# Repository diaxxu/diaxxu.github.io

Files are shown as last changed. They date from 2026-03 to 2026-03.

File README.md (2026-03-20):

#  DROP POD — Precision Aerial Delivery System

Capture d'écran 2026-03-20 113256

<p align="center">
  
  
  
  
  
</p>

---

> **A fully autonomous, GPS + vision-guided drop pod** carried under the wing of an RC aircraft. Released on operator command, it navigates to a red carpet landing zone using GPS macro-guidance and nose-mounted optical terminal tracking — nose-first impact, cushion-assisted landing. No propulsion. No parachute. Pure precision.

---

##  Table of Contents

1. [What This Is](#what-this-is)
2. [How It Works](#how-it-works)
3. [System Architecture](#system-architecture)
4. [Hardware Requirements](#hardware-requirements)
5. [Software Stack](#software-stack)
6. [Directory Structure](#directory-structure)
7. [Quick Start](#quick-start)
8. [Wiring Guide](#wiring-guide)
9. [Configuration](#configuration)
10. [Flight Operations](#flight-operations)
11. [Tuning Guide](#tuning-guide)
12. [Safety & Legal](#safety--legal)
13. [Contributing](#contributing)
14. [Roadmap](#roadmap)
15. [Team & Credits](#team--credits)

---

## What This Is

The **Drop Pod** is a passively propelled, actively guided aerial payload delivery system. It is:

- **Carried** under the wing of any medium RC aircraft (minimum 1.5 kg payload capacity)
- **Released** on operator command (RC transmitter aux channel or GCS MAVLink command)
- **Self-guided** using onboard GNSS to the target zone
- **Optically locked** onto a red carpet marker using a nose-mounted camera running real-time OpenCV detection
- **Nose-impact landed** — the pod dives nose-first onto the cushioned target

**Phase 1 scope (this repository):** GPS approach + optical lock + direct nose-impact. No flare. No glide slope. Ground team places a foam/air cushion on the red carpet. The pod hits it clean.

---

## How It Works

```
┌─────────────────────────────────────────────────────────────────┐
│                        MISSION TIMELINE                         │
└─────────────────────────────────────────────────────────────────┘

  [GROUND]                [IN-AIR]                    [TERMINAL]
  
  Load target GPS    →   Carrier delivers pod   →   Pod descends
  Arm system             over drop zone             GPS-guided
  Confirm carpet         ↓                          ↓
  is in range            Operator sends             At ~40m AGL:
  ↓                      ARM → DROP                 Camera activates
  Cushion placed         ↓                          Red carpet locked
  on carpet              Reachability check         Optical steering
                         passes                     ↓
                         ↓                          Nose-impact on
                         Latch fires                cushion ✓
                         Pod separates
```

### Phase Breakdown

| Phase | Mode | Altitude | Trigger |
|---|---|---|---|
| **Idle** | Passive on wing | Any | — |
| **Armed** | Monitoring | Any | ARM command |
| **Released** | Stabilised descent | Drop alt | DROP command + reach check |
| **GPS Approach** | GNSS-guided | Drop → 40 m AGL | Automatic post-release |
| **Optical Lock** | Camera tracking | 40 m → impact | Barometer threshold |
| **Landed** | Inert | 0 | Impact detection (accel) |

---

## System Architecture

```
┌────────────────────────────────────────────────────────────┐
│                    DROP POD INTERNALS                      │
│                                                            │
│  [NOSE — CAMERA]                                           │
│  ┌─────────────────────────────────────┐                   │
│  │  RPi Camera Module 3 (CSI-2)        │ ← Nose tip        │
│  │  IMX708 · 102° FOV · 30fps          │   looking forward │
│  └──────────────┬──────────────────────┘                   │
│                 │ CSI ribbon                               │
│  [FORWARD SECTION — COMPUTE + FINS]                        │
│  ┌──────────────▼──────────────────────┐                   │
│  │  Raspberry Pi Zero 2W               │ ← Vision + FSM    │
│  │  ├─ mission_manager.py              │                   │
│  │  ├─ vision.py (OpenCV)              │                   │
│  │  └─ UART → FC (MAVLink/MSP)         │                   │
│  │                                     │                   │
│  │  Matek F405-WING (ArduPlane)        │ ← PID + Servos    │
│  │  ├─ IMU ICM-42688 (SPI)             │                   │
│  │  ├─ GPS u-blox M10 (UART)          │                   │
│  │  ├─ Baro BMP388 (I2C)              │                   │
│  │  └─ 4× Servo PWM outputs           │                   │
│  │                                     │                   │
│  │  4× Canard Fins (cruciform)         │ ← Actuation       │
│  │  Emax ES9051 · 2.0 kg·cm           │                   │
│  └─────────────────────────────────────┘                   │
│                                                            │
│  [MID SECTION — POWER + COMMS]                             │
│  ┌─────────────────────────────────────┐                   │
│  │  3S 1000mAh LiPo (11.1V)           │ ← Main power       │
│  │  Pololu 5V BEC ×2                   │                   │
│  │  ELRS Receiver (2.4GHz SBUS)        │ ← RC commands      │
│  │  SiK 915MHz Telemetry               │ ← GCS MAVLink      │
│  └─────────────────────────────────────┘                   │
└────────────────────────────────────────────────────────────┘
```

### Inter-Processor Communication

```
RC TX (pilot)  ──SBUS──►  ELRS Receiver ──SBUS──► F405 FC
                                                      │
GCS (laptop)   ──MAVLink/915MHz──────────────────────►│
                                                      │
                                            F405 FC ◄─┤─► 4× Servo (PWM 400Hz)
                                               │      │
                                           UART/MSP   │
                                               │      │
                                        RPi Zero 2W   │
                                               │      │
                                         CSI-2 │      │
                                               │      │
                                        Camera Module  │
```

---

## Hardware Requirements

See [BOM.csv](BOM.csv) for complete sourcing list. Summary:

| # | Component | Purpose | Est. Cost |
|---|---|---|---|
| 1 | **Matek F405-WING** | Flight controller, PID, servo output | $35 |
| 2 | **Raspberry Pi Zero 2W** | Vision compute, mission FSM | $15 |
| 3 | **RPi Camera Module 3 Wide** | Nose-mounted target tracking | $25 |
| 4 | **u-blox M10 GPS** | GNSS macro-approach guidance | $30 |
| 5 | **ICM-42688-P IMU** | Attitude estimation (may be on FC) | $8 |
| 6 | **BMP388 Barometer** | AGL altitude for camera activation | $5 |
| 7 | **SiK 915MHz Radio ×2** | GCS MAVLink telemetry + uplink | $30 |
| 8 | **ELRS Receiver** | RC TX commands (ARM/DROP) | $12 |
| 9 | **9g Digital Servo ×5** | 4× fin + 1× wing latch | $20 |
| 10 | **3S 1000mAh LiPo** | Main power | $18 |
| 11 | **Pololu 5V BEC ×2** | Regulated power rails | $10 |
| 12 | **CF Tube ø80×320mm** | Main fuselage | $15 |
| 13 | **PETG/PLA Filament** | Printed structure parts | $10 |
| **Total** | | | **~$233** |

### Carrier Aircraft Requirements

- Minimum payload capacity: **800g** (pod target mass ≤ 650g)
- Wing hardpoint or pod-rail mounting point
- Free aux channel on RC TX for release servo
- Stable flight at 12–22 m/s

---

## Software Stack

| Layer | Technology | Purpose |
|---|---|---|
| Flight controller | ArduPlane (STM32) | PID, servo mixing, GPS nav |
| Vision + FSM | Python 3.11 on RPi | OpenCV, mission state machine |
| Inter-proc comms | MAVLink over UART | Pi ↔ FC bidirectional |
| GCS | Mission Planner / MAVProxy | Ground control, telemetry display |
| Configuration | YAML + .param files | All tunable params in one place |

---

## Directory Structure

```
drop-pod/
│
├── README.md                    ← You are here
├── BOM.csv                      ← Full bill of materials with sourcing
├── LICENSE                      ← MIT License
│
├── software/                    ← All Python code for RPi
│   ├── requirements.txt         ← pip dependencies
│   ├── config.py                ← Central configuration (all tunable params)
│   ├── mission_manager.py       ← Main mission FSM — entry point
│   ├── vision.py                ← OpenCV red carpet detection pipeline
│   ├── guidance.py              ← Reachability check + GPS math
│   └── comms.py                 ← MAVLink interface (FC + GCS)
│
├── firmware/
│   ├── params/
│   │   └── drop_pod.param       ← ArduPlane parameter file (load via MP)
│   └── lua/
│       └── vision_inject.lua    ← ArduPlane Lua: ingest Pi corrections
│
├── hardware/
│   ├── stl/
│   │   ├── README.md            ← Print settings for every part
│   │   ├── nose_camera_mount.stl
│   │   ├── fin_mount_forward.stl
│   │   ├── fin_blade.stl
│   │   ├── servo_bay_cover.stl
│   │   ├── avionics_tray.stl
│   │   ├── power_bay.stl
│   │   └── tail_cap_camera_exit.stl   ← NOTE: camera is at nose, this is ballast
│   └── wiring/
│       └── wiring_diagram.md    ← Full pinout and wiring guide
│
├── docs/
│   ├── MECHANICAL.md            ← Dimensions, CG, fin geometry
│   ├── ASSEMBLY.md              ← Step-by-step build guide
│   ├── TUNING.md                ← PID tuning procedure
│   ├── SAFETY.md                ← Pre-flight checklist, regulations
│   └── FLIGHT_OPS.md            ← Field operations manual
│
└── .github/
    └── CONTRIBUTING.md          ← How to contribute
```

---

## Quick Start

### 1. Clone the Repository

```bash
git clone https://github.com/your-org/drop-pod.git
cd drop-pod
```

### 2. Set Up the Raspberry Pi Zero 2W

```bash
# Flash Raspberry Pi OS Lite (64-bit) onto SD card
# Enable SSH, I2C, SPI, Camera in raspi-config

# On the Pi:
sudo apt update && sudo apt install -y python3-pip python3-opencv libopencv-dev
cd /home/pi
git clone https://github.com/your-org/drop-pod.git
cd drop-pod/software
pip3 install -r requirements.txt

# Edit config before first run
nano config.py
```

### 3. Configure the Flight Controller

```
1. Flash ArduPlane latest stable to your F405
2. Open Mission Planner → Full Parameter List
3. Load firmware/params/drop_pod.param
4. Calibrate: accelerometer, compass, radio
5. Set SERVO1..4 outputs to match your fin wiring
```

### 4. Connect Telemetry

```bash
# On ground laptop:
mavproxy.py --master=/dev/ttyUSB0 --baudrate=57600 --out=udp:127.0.0.1:14550
# Open Mission Planner → connect UDP 14550
```

### 5. Set Target Coordinates

```python
# In software/config.py:
TARGET_LAT  = 33.5731  # Decimal degrees
TARGET_LON  = -7.5898
TARGET_ALT  = 0.0      # MSL in metres (ground elevation)
```

### 6. Pre-Flight Checklist

See [docs/SAFETY.md](docs/SAFETY.md) for complete pre-flight checklist.

---

## Wiring Guide

See [hardware/wiring/wiring_diagram.md](hardware/wiring/wiring_diagram.md) for complete pinout.

Quick reference:

```
F405 FC                     RPi Zero 2W
──────────                  ──────────
TX1 (UART1) ─────────────► RX (GPIO15 / UART0)
RX1 (UART1) ◄───────────── TX (GPIO14 / UART0)
GND ─────────────────────── GND

F405 FC                     ELRS Receiver
──────────                  ─────────────
RX2 (UART2) ◄───────────── SBUS OUT
5V BEC ─────────────────── 5V
GND ─────────────────────── GND

F405 FC                     u-blox M10 GPS
──────────                  ──────────────
TX3 (UART3) ─────────────► RX
RX3 (UART3) ◄───────────── TX
5V ─────────────────────── 5V
GND ─────────────────────── GND

F405 FC                     Servos (×4 fins + 1 latch)
──────────                  ──────────────────────────
S1 ────────────────────────► FIN TOP (signal)
S2 ────────────────────────► FIN BOTTOM (signal)
S3 ────────────────────────► FIN LEFT (signal)
S4 ────────────────────────► FIN RIGHT (signal)
S5 ────────────────────────► LATCH SERVO (on carrier aircraft)
Servo BEC 5V ──────────────► All servo 5V rails (common)
GND ───────────────────────► All servo GND (common)
```

---

## Configuration

All mission-tunable parameters live in `software/config.py`:

```python
# ── MISSION ──────────────────────────────────────────────
TARGET_LAT          = 33.5731       # Target latitude
TARGET_LON          = -7.5898       # Target longitude
TARGET_ALT_MSL      = 0.0           # Ground elevation MSL (m)

# ── REACHABILITY ─────────────────────────────────────────
GLIDE_RATIO         = 4.0           # Conservative glide ratio
SAFETY_MARGIN       = 0.85          # Use only 85% of max range
MAX_WIND_SPEED      = 8.0           # m/s — abort above this

# ── PHASE TRANSITIONS ────────────────────────────────────
CAMERA_ACTIVATE_AGL = 40.0          # metres — switch to optical
MIN_LOCK_CONFIDENCE = 0.80          # 0.0–1.0, red carpet lock threshold

# ── VISION ───────────────────────────────────────────────
CAM_FOV_H_DEG       = 102.0         # Camera horizontal FOV
CAM_FOV_V_DEG       = 67.0          # Camera vertical FOV
CAM_RESOLUTION      = (1280, 720)   # Capture resolution
CAM_FPS             = 30            # Target frame rate
HSV_RED_LOW_1       = (0,   120, 80)    # Red mask range 1 lower
HSV_RED_HIGH_1      = (12,  255, 255)   # Red mask range 1 upper
HSV_RED_LOW_2       = (165, 120, 80)    # Red mask range 2 lower
HSV_RED_HIGH_2      = (180, 255, 255)   # Red mask range 2 upper
MIN_CARPET_AREA_PX  = 800           # Min blob pixels to count as lock

# ── GUIDANCE GAINS ───────────────────────────────────────
KV_LATERAL          = 0.4           # Vision lateral correction gain
KV_PITCH            = 0.15          # Vision pitch correction gain

# ── COMMUNICATION ────────────────────────────────────────
FC_UART_PORT        = "/dev/serial0"
FC_UART_BAUD        = 115200
TELEM_BAUD          = 57600
HEARTBEAT_INTERVAL  = 0.5           # seconds
```

---

## Flight Operations

### Pre-Mission Checklist (Field)

```
□ Battery voltage > 12.0V (3S full = 12.6V)
□ GPS 3D fix acquired, HDOP < 2.0
□ All 4 fins deflect correctly (servo test)
□ Camera feed active, red carpet detected in bench test
□ Telemetry link established on GCS
□ Target coordinates loaded and verified
□ Red carpet placed at target, cushion on top
□ Drop zone clear of personnel (minimum 30m radius)
□ Weather: wind < 8 m/s, no rain
□ Carrier aircraft pre-flight complete
□ Carrier release servo tested (WITHOUT pod attached)
```

### Drop Sequence

```
1. Carrier aircraft takes off, climbs to mission altitude (min 60m AGL)
2. Pilot flies over or near drop zone
3. GCS operator confirms pod GPS position and range
4. Operator sends: ARM command (TX Ch7 HIGH or GCS button)
5. GCS shows: "POD ARMED — REACHABILITY CHECK ACTIVE"
6. If target in range: GCS shows "IN RANGE — SAFE TO DROP"
7. Operator sends: DROP command (TX Ch8 HIGH or GCS button)
8. Pod releases, begins GPS-guided descent
9. At 40m AGL: GCS shows "CAMERA ACTIVE"
10. At lock: GCS shows "TARGET LOCKED — [confidence]%"
11. Pod impacts cushion on red carpet
12. GCS shows "LANDED" (accel spike detected)
```

### GCS Commands (MAVLink)

| Action | Mission Planner | MAVProxy CLI |
|---|---|---|
| ARM | Aux1 HIGH button | `param set RELAY_PIN1 1` |
| DROP | Aux2 HIGH button | `do_set_relay 1 1` |
| ABORT | Abort button | `mode GUIDED` |
| Update target | Right-click map → Set target | `guided LAT LON ALT` |

---

## Tuning Guide

See [docs/TUNING.md](docs/TUNING.md) for full procedure. Key steps:

1. **Bench test**: Verify all servos zero correctly with no power-on drift
2. **Hand-drop test**: Drop from 2m by hand. Verify fins stabilise attitude within 0.5s
3. **Low-altitude drop**: 15–20m from a tall pole or drone. Verify GPS tracks target
4. **Vision bench**: Move red carpet under camera. Verify centroid tracks correctly at 1m, 3m, 5m
5. **Full mission**: 60m+ drop with camera active at 40m. Evaluate impact accuracy

---

## Safety & Legal

 **Read [docs/SAFETY.md](docs/SAFETY.md) before any field test.**

- This system drops a ~650g object from altitude. Treat it as a **projectile**.
- Always operate in a **cleared, controlled area** with ground personnel outside the drop radius.
- **National regulations apply.** In EU: EASA UAS open/specific category rules. In the US: FAA Part 107 may require a waiver for dropping objects.
- Use the two-step ARM → DROP command sequence. Never skip ARM.
- The reachability check is a safety gate — **do not bypass it in code**.

---

## Roadmap

### Phase 1 — Current (This Repo)
- [x] GPS macro-approach guidance
- [x] Nose-camera optical red carpet lock
- [x] 4-fin canard attitude control
- [x] RC + GCS dual command interface
- [x] Reachability check with automatic abort
- [x] Nose-impact delivery (cushion-assisted)

### Phase 2 — Next
- [ ] RTK GPS for cm-level approach accuracy
- [ ] YOLOv8-nano detector replacing HSV (shadow-robust)
- [ ] LiDAR AGL sensor (TFMini) for precise altitude
- [ ] Controlled flare manoeuvre for softer landing

### Phase 3 — Future
- [ ] Two-way camera feed via 5.8GHz VTX
- [ ] Swappable payload bay
- [ ] Multiple concurrent pods on one carrier
- [ ] Sim-to-real training loop (Gazebo/AirSim)

---

## Contributing

See [.github/CONTRIBUTING.md](.github/CONTRIBUTING.md).

PRs welcome in these areas:
- Better PID initial values (share your tuning data)
- Alternative vision algorithms
- 3D model improvements
- Documentation translations
- Simulation environments (Gazebo/AirSim configs)

---
## License

MIT License — see [LICENSE](LICENSE). Free to use, modify, and build. Please credit the project.

---

<p align="center">
  <strong>DROP POD — OPEN SOURCE PRECISION DELIVERY</strong><br/>
  <em>If it can be guided, it can be landed precisely.</em>
</p>

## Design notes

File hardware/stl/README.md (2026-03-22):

# 3D Printed Parts — Print Settings & Assembly Guide
## Drop Pod Hardware Revision A

---

## Printer Requirements

| Parameter | Minimum | Recommended |
|---|---|---|
| Build volume | 100×100×100mm | 200×200×200mm |
| Layer resolution | 0.2mm | 0.15mm |
| Extruder temp | 230°C (PETG) | 240°C |
| Bed temp | - | 80°C |
| Bed surface | PEI/glass | PEI textured |

---

## Material

**Use PETG for ALL structural parts.** Do NOT use PLA.

| Property | PLA | PETG |
|---|-----|---|
| Impact resistance | Low | High |
| Heat deflection | ~60°C (warps in sun) | ~80°C |
| Layer adhesion | Medium | High |
| Price | Cheaper | Slightly more |

Impact resistance is critical — the pod noses into a cushion at speed. PETG absorbs impact energy significantly better than PLA.

---

## Parts List

### Part 01: `nose_camera_mount.stl`
**The nose of the pod — this IS the camera housing.**

```
Description : Cylindrical nose section, ø80mm OD, 85mm long.
              Camera Module 3 Wide seats in a recessed pocket at
              the very tip. CSI ribbon exits through a slot in
              the side wall toward the avionics bay.
              
Function    : Camera housing + aerodynamic nose fairing.
              The camera lens is flush with the front face.
              
Print settings:
  - Layer height : 0.15mm (critical for lens pocket accuracy)
  - Infill       : 40% gyroid
  - Walls        : 4 perimeters
  - Top/bottom   : 5 layers
  - Supports     : YES — needed for camera pocket recess
  - Orientation  : Print nose-tip UP for best surface quality on lens face
  
Post-processing:
  - Sand camera pocket with 400-grit until Camera Module 3
    sits flush with no wobble
  - Apply thin bead of hot glue around camera module edges
    to lock in place (do not glue over lens)
  - Thread CSI ribbon through side slot before gluing camera
  - Bond to CF tube with 30-min epoxy. Align with fin mount slots.
```

### Part 02: `fin_mount_forward.stl`
**Servo bay ring — slides into CF tube, holds 4 servos.**

```
Description : Ring-shaped collar, ø80mm OD to match CF tube ID.
              Four servo pockets, cruciform pattern at 90° spacing.
              Servo horns face inward.
              
Print settings:
  - Layer height : 0.2mm
  - Infill       : 60% gyroid (strength critical)
  - Walls        : 5 perimeters
  - Top/bottom   : 5 layers
  - Supports     : Minimal — servo pockets may need tree supports
  - Orientation  : Print in the mounting orientation (ring flat on bed)

Post-processing:
  - Test-fit all 4 servos before final assembly
  - Drill out M3 screw holes with 3.2mm drill bit if tight
  - Apply Loctite 243 to all servo mount screws
```

### Part 03: `fin_blade.stl`
**Canard fin — print 4 identical copies.**

```
Description : Trapezoidal fin blade, 55mm span × 40mm chord.
              NACA 0009 profile (symmetrical, zero camber).
              Servo horn attachment slot at root.
              Pushrod clevis attachment hole at trailing edge root.
              
Print settings:
  - Layer height : 0.15mm (profile accuracy)
  - Infill       : 30% triangles (strong in bending)
  - Walls        : 4 perimeters
  - Top/bottom   : 4 layers
  - Supports     : None needed
  - Orientation  : Print FLAT on bed (fin in horizontal plane)
  - Note         : Print ALL FOUR in same batch for matching mass

Post-processing:
  - Sand trailing edge to sharp edge with 400-grit
  - Check all 4 fins have same mass (±0.5g). Add tiny epoxy
    drops to lighter fins to balance.
  - Attach servo horn to root slot. Use M2 screw + Loctite.
```

### Part 04: `servo_bay_cover.stl`
**Aesthetic/protective cover over the servo bay area.**

```
Description : Thin cylindrical skin section, 80mm OD × 50mm long.
              Four slots cut for fin root protrusion.
              Snaps over fin_mount_forward.
              
Print settings:
  - Layer height : 0.2mm
  - Infill       : 20%
  - Walls        : 3 perimeters
  - Supports     : None
  - Orientation  : Vertical (cylinder axis vertical on bed)
```

### Part 05: `avionics_tray.stl`
**Internal mounting tray for FC, Pi, GPS.**

```
Description : Rectangular tray, 70mm × 150mm × 10mm.
              Slots for M3 nylon standoffs at FC and Pi footprints.
              Slides into CF tube and is retained by M3 screws
              through the CF tube wall.
              
Print settings:
  - Layer height : 0.2mm
  - Infill       : 40% gyroid
  - Walls        : 4 perimeters
  - Supports     : None
  - Orientation  : Flat on bed

Component placement on tray (front to back):
  [0mm]   GPS module (UART3, antenna pointing up through hole in tray)
  [30mm]  F405 FC (SPI/I2C sensors connect here)
  [80mm]  RPi Zero 2W (UART0 → FC UART1)
  [130mm] SiK radio module
```

### Part 06: `power_bay.stl`
**Battery bay and BEC holder — rear section of pod.**

```
Description : Cylindrical section, 80mm OD × 90mm long.
              Battery cradle sized for 3S 1000mAh (18×35×72mm approx).
              Two BEC holders on sides.
              XT30 port slot at rear.
              
Print settings:
  - Layer height : 0.2mm
  - Infill       : 35%
  - Walls        : 4 perimeters
  - Supports     : YES for battery cradle lip
  - Orientation  : Print with XT30 port face UP

Battery retention:
  - Two Velcro straps through slots in cradle
  - Do NOT rely on friction alone — battery must not shift under impact
```

### Part 07: `tail_ballast_cap.stl`
**Rear end cap with ballast weight pocket.**

```
Description : Domed end cap, 80mm OD.
              Central ballast pocket for tungsten or steel slug.
              Plug-in fit with rubber O-ring for retention.
              
Print settings:
  - Layer height : 0.2mm
  - Infill       : 50% (structural for ballast retention)
  - Walls        : 5 perimeters
  - Supports     : None
  - Orientation  : Dome up on bed

CG Note:
  Target CG location: 30% of total body length from nose.
  Add/remove ballast weight in this cap to tune CG.
  A nose-heavy pod is more stable; tail-heavy causes tumbling.
  Test CG on assembled pod: balance on a round rod at 30% point.
```

### Part 08: `wing_saddle_mount.stl`
**Mounting saddle that attaches to carrier aircraft wing.**

```
Description : Wing saddle, curved to fit wing profile of carrier.
              Two M4 bolt through-holes for wing attachment.
              Pod-rail slot (20mm wide) for pod to slide in.
              Latch retention pin hole (M3 diameter).
              
Print settings:
  - Layer height : 0.15mm (mounting accuracy)
  - Infill       : 80% (maximum strength — structural)
  - Walls        : 6 perimeters
  - Top/bottom   : 6 layers
  - Supports     : YES — curved base needs support
  - Material     : PETG (or Carbon-fibre PETG for extra strength)

IMPORTANT: This part takes the full impact load of separation.
Print with maximum infill and wall count. Inspect after every flight.
Replace if any cracking appears.
```

---

## Assembly Order

```
1. Print all parts (2–3 hour total print time)
2. Test-fit nose_camera_mount to CF tube — should be snug, not loose
3. Install servos into fin_mount_forward ring
4. Thread pushrods through fin slots, attach to servo horns (Z-bend)
5. Attach fin blades to pushrod clevis ends
6. Slide fin_mount_forward + fins assembly into CF tube front
7. Install avionics_tray with FC, Pi, GPS into CF tube mid-section
8. Install power_bay with battery and BECs at rear
9. Install tail_ballast_cap — add initial ballast (50g)
10. Attach nose_camera_mount (with camera already installed)
11. Route all cables: UART (FC→Pi), servo wires, GPS, power
12. BEFORE sealing: CG check. Balance point must be at 28-32% from nose
13. Adjust ballast until CG is correct
14. Final assembly: epoxy all section joints
15. Install on wing_saddle_mount on carrier aircraft
```

---

## CG Check Procedure

```
1. Assemble pod completely with battery at its planned position
2. Balance pod on a 5mm round rod at 95mm from nose (30% of 320mm)
3. Pod should balance level or very slightly nose-heavy
4. If tail-heavy: move battery forward, or add ballast to nose_camera_mount
5. If very nose-heavy: move battery rearward, or reduce ballast weight
6. Never fly tail-heavy — this causes tumbling and loss of control
```

Target CG: **95–105mm from nose tip**

---

## Post-Print Finishing

1. **Deburr** all holes with a 3mm drill bit by hand
2. **Sand** any rough layer lines on aerodynamic surfaces with 400-grit
3. **Test-fit** every servo before final assembly
4. **Hot-glue** all cable routing to prevent vibration chafing
5. **Mark** each fin with a number (1-4) and corresponding servo number
6. **Photograph** internal wiring before closing pod — invaluable for troubleshooting

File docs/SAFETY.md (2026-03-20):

# Safety Guide & Pre-Flight Checklist
## Drop Pod — Mandatory Reading Before Any Field Operation

---

> **This document must be read by every person involved in a drop pod operation.**
> The pod is a guided projectile. Treat it with the same respect as any object launched from height.

---

## Risk Assessment

| Hazard | Severity | Probability | Mitigation |
|---|---|---|---|
| Pod impacts person | Critical | Low (with protocols) | Ground exclusion zone, ARM verification |
| Pod drifts off-target | Moderate | Medium | Reachability check, wind limit |
| Battery fire (LiPo) | High | Low (with handling protocols) | Safe LiPo procedures, check voltage before flight |
| GPS signal loss | Moderate | Low | Watchdog: degrades gracefully, no abrupt changes |
| Accidental release on ground | Critical | Low | Two-stage ARM→DROP, arming check |
| Camera miss / wrong target | Moderate | Medium | Bench-test HSV thresholds before each field op |

---

## Exclusion Zone

**Before any drop:**

```
                    ┌─────────────┐
                    │  TARGET     │ ← Red carpet + cushion
                    │  ZONE       │
                    └─────────────┘
    ←──────── MINIMUM 30m RADIUS ────────►
    
    NO PERSONNEL inside this radius
    during any DROP operation.
    
    Exception: the person who placed the cushion.
    They must exit the zone before ARM command is issued.
```

Establish the exclusion zone with:
- Physical barrier (cones, tape)
- Radio communication with all team members
- Visual confirmation before ARM

---

## Two-Stage Safety Gates

The system has two mandatory gates before the pod can be released:

```
GATE 1 — ARM
  Required: Explicit ARM command (TX CH7 HIGH or GCS button)
  System checks: GPS fix valid, HDOP < 3.0
  On pass: system enters ARMED state, monitors reachability
  
  ↓ (only after GATE 1 passes)
  
GATE 2 — REACHABILITY CHECK (automatic, runs on DROP command)
  Checks: horizontal distance ≤ (alt_agl × glide_ratio × 0.85)
  Checks: altitude ≥ MIN_RELEASE_AGL (40m default)
  On fail: DROP is silently rejected, GCS notified
  On pass: latch fires, mission begins
```

**Never modify the reachability check logic to force it to pass.** It exists to prevent the pod from landing outside the target area.

---

## Pre-Flight Checklist

Run this checklist in order before every flight. No shortcuts.

### A — Site Preparation
```
□ Landing zone surveyed, obstruction-free (30m radius)
□ Red carpet placed flat, no wrinkles or folds
□ Impact cushion centred on red carpet
□ Target GPS coordinates measured and loaded into config.py
□ Ground personnel briefed on exclusion zone
□ Communication established with all team members
□ First aid kit on site
□ Emergency abort procedure agreed upon
```

### B — Weather Check
```
□ Wind speed: measured at site (anemometer or phone app)
  - Green: < 4 m/s
  - Yellow: 4–6 m/s (reduced accuracy expected)
  - Red/No-fly: > 8 m/s  ← ABORT
□ No rain forecast during operation window
□ Visibility > 500m (can see pod throughout flight)
□ Sun angle not directly into pilot's/camera's field of view
```

### C — Electrical Check (Before Mounting on Aircraft)
```
□ LiPo voltage ≥ 12.3V (3S — do not fly below 12.0V)
□ LiPo shows no swelling, no damage to leads
□ All servo connectors seated and secure
□ GPS antenna seated and not cracked
□ Camera lens clean and clear
□ ELRS receiver LED indicating bound status
□ SiK radio LED indicating link to GCS
```

### D — Software Check
```
□ Pi mission manager started: python3 software/mission_manager.py
□ GCS Mission Planner connected, telemetry streaming
□ GPS 3D fix acquired: HDOP < 2.0, sats ≥ 8
□ Target coordinates verified on GCS map (marker at correct location)
□ Reachability check tested from ground (should say OUT OF RANGE from ground)
□ Vision test: camera feed active, red carpet detected in bench test
□ RC bind confirmed: all channels responding on GCS RC screen
□ ARM channel (CH7) verified: stick/switch moves correct channel
□ DROP channel (CH8) verified: stick/switch moves correct channel
□ ABORT channel (CH9) verified: accessible, tested
```

### E — Carrier Aircraft Check
```
□ Carrier aircraft pre-flight complete per its own checklist
□ Latch servo tested with pod: PIN ENGAGED, pod does not slide out
□ Latch servo tested: PIN RETRACTED at DROP command (test WITHOUT pod first)
□ Pod re-installed, pin engaged, pull-test: pod does not release under 5N pull
□ Servo extension cable has adequate slack, secured at regular intervals
□ Pod CG re-verified after installation on carrier
□ Combined carrier + pod CG acceptable for carrier aircraft flight envelope
```

---

## In-Flight Abort Procedure

If at any point during the flight the operator decides to abort:

1. **ABORT command**: TX CH9 HIGH or GCS Abort button
2. This transitions the pod to ABORT state: all optical corrections disabled, pod holds last attitude
3. **If pod has already been released**: it will continue to descend with no guidance correction (flat attitude hold)
4. **If release has NOT happened**: do not issue DROP — fly carrier back and land with pod attached

If carrier aircraft loses control with pod attached:
- The pod will remain attached until latch is actively commanded
- Only command DROP if carrier is already in a safe recovery trajectory
- Otherwise land carrier with pod attached

---

## LiPo Safety Protocol

```
CHARGING
  - Never charge unattended
  - Use balance charger (all cells must balance to ±0.05V)
  - Max charge rate: 1C (1.0A for 1000mAh)
  - Never charge below 3.0V/cell (cell may be permanently damaged)
  
STORAGE
  - Store at 3.8V/cell (storage charge)
  - Store in LiPo-safe bag or metal ammo box
  - Never in hot vehicle (> 40°C)
  - Inspect before each use for swelling

DISPOSAL
  - Discharge completely to 3.0V/cell using a discharge resistor
  - Submerge in salt water for 2 weeks (renders cell inert)
  - Then dispose as electronic waste
  
IN-FLIGHT LOW BATTERY
  - GCS will alert at 3.4V/cell
  - Abort mission, fly carrier back immediately
  - Never fully deplete mid-flight — over-discharge destroys cells permanently
```

---

## Regulatory Notes

> **This section does not constitute legal advice. Consult your national aviation authority.**

| Country | Authority | Key Requirement |
|---|---|---|
| Morocco | ANAC | UAS ops require authorisation; dropping objects may need specific waiver |
| EU | EASA | Specific category UAS ops; dropping objects requires PDRA or STS |
| USA | FAA | Part 107 rule 107.23 prohibits dropping objects that create hazard — waiver needed |
| UK | CAA | OSC required for dropping objects from UAS |

**General principles (apply everywhere):**
- Always operate in unpopulated areas
- Never drop over or near roads, buildings, or crowds
- Maintain Visual Line of Sight (VLOS) with both carrier and pod
- Log all flights (date, location, altitude, operator)
- Carry third-party liability insurance

---

## Emergency Contacts

Fill in before field operations:

```
Local ATC / NOTAM office: _______________________
Team lead phone:          _______________________
Nearest hospital:         _______________________
Emergency services:       _______________________
```

---

## Incident Reporting

If the pod impacts outside the target zone, impacts infrastructure, or causes any injury:

1. Ensure all personnel are safe
2. Do not move any wreckage
3. Photograph the scene
4. Record: time, weather conditions, telemetry log, last known GPS position
5. Report to national aviation authority per their incident reporting procedure
6. Open a GitHub issue in this repository with logs (anonymised if needed)

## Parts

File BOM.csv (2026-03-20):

ID | Category | Component | Description | Qty | Unit_Price_USD | Total_USD | Supplier | Part_Number | Link_or_Search | Notes
BOM-001 | Flight Controller | Matek H743-WING v3 | STM32H743 flight controller – ArduPlane compatible – integrated baro OSD BEC | 1 | 45.00 | 45.00 | Matek / GetFPV / RCGroups | MK-H743-WING | Search: Matek H743-WING | H743 preferred over F405 for processing headroom; F405-WING also compatible at lower cost
BOM-002 | Vision Computer | Raspberry Pi Zero 2W | ARM Cortex-A53 × 4 – 512MB RAM – CSI-2 camera interface – Wi-Fi | 1 | 15.00 | 15.00 | Raspberry Pi / Adafruit / PiShop | SC0510 | raspberrypi.com | Solder 40-pin header. Use Lite OS image (headless).
BOM-003 | Camera Module | RPi Camera Module 3 Wide | Sony IMX708 – 102° FOV – 12MP – CSI-2 – 1080p30 | 1 | 25.00 | 25.00 | Raspberry Pi / PiHut | SC0872 | raspberrypi.com | NOSE-MOUNTED — this is the nose of the pod. Mount facing forward/downward direction of travel.
BOM-004 | GNSS | u-blox M10 GPS Module | Concurrent GNSS GPS+GLO+GAL – 10 Hz – UART – patch antenna | 1 | 30.00 | 30.00 | SparkFun / Matek | GPS-18037 / M10Q-120 | sparkfun.com Search: u-blox M10 | Mount inside nose section above camera, patch antenna must face sky
BOM-005 | IMU | ICM-42688-P Breakout | 6-axis IMU – 32kHz ODR – SPI – low-noise – ±2000dps gyro | 1 | 8.00 | 8.00 | SparkFun / Adafruit | SEN-21829 | sparkfun.com Search: ICM-42688 | Often integrated in FC — check if F405/H743 variant includes it. Buy separately only if FC IMU is insufficient.
BOM-006 | Barometer | BMP388 Breakout | High-precision barometer – I2C/SPI – ±0.5hPa – 200Hz ODR | 1 | 5.00 | 5.00 | Adafruit / SparkFun | SEN-16832 | adafruit.com #3966 | Usually integrated in FC. Buy separately if FC lacks baro or for redundancy.
BOM-007 | Telemetry | SiK 915MHz Telemetry Radio V3 (pair) | Bidirectional MAVLink – 100mW – UART – up to 3km LOS – pair | 1 | 28.00 | 28.00 | RFDesign / Holybro / mRobotics | mRo SiK Telem V3 | Search: SiK 915MHz telemetry pair | Pair = 1 for pod, 1 for GCS laptop. Use 433MHz if 915 is not legal in your country.
BOM-008 | RC Receiver | BetaFPV ELRS Lite Receiver | ExpressLRS 2.4GHz – SBUS output – <1ms latency – >1km range | 1 | 12.00 | 12.00 | BetaFPV / GetFPV | ELRS-LITE-RX | betafpv.com | Requires ELRS-compatible TX. Alternatively use FrSky XM+ with FrSky TX.
BOM-009 | Servo – Fins | Emax ES9051 Digital 9g Servo × 4 | Digital 9g – 2.0 kg·cm – 0.09s/60° – 4.8–6V – metal gear | 4 | 4.50 | 18.00 | Emax / GetFPV / Amazon | ES9051 | emaxmodel.com | 4 pieces needed — one per canard fin. Digital essential for hold torque and precision.
BOM-010 | Servo – Latch | Emax ES9051 Digital 9g Servo | Same as fins — used for carrier aircraft wing latch release | 1 | 4.50 | 4.50 | Emax / GetFPV / Amazon | ES9051 | emaxmodel.com | Mounted on CARRIER AIRCRAFT wing hardpoint. Pulls retention pin to release pod.
BOM-011 | Battery | CNHL 3S 1000mAh 30C LiPo | 3S – 11.1V – 1000mAh – 30C – XT30 – ~70g | 1 | 16.00 | 16.00 | CNHL / Tattu / GNB | CNHL-3S-1000-30C | Search: 3S 1000mAh 30C LiPo XT30 | Mounted in mid-body for CG. Adjust position fore/aft to tune CG to 28% body length from nose.
BOM-012 | BEC 1 | Pololu D24V22F5 5V/2.2A Step-Down | 5V – 2.2A – 98% efficient – 4–38V input – compact | 1 | 7.95 | 7.95 | Pololu | #2858 | pololu.com/product/2858 | Powers FC + RPi Zero + GPS + sensors. Separate from servo BEC to isolate noise.
BOM-013 | BEC 2 | Pololu D24V22F5 5V/2.2A Step-Down | 5V – 2.2A – 98% efficient – 4–38V input – compact | 1 | 7.95 | 7.95 | Pololu | #2858 | pololu.com/product/2858 | Powers all 5 servos. Separate BEC mandatory — servo transients destroy FC/Pi if shared.
BOM-014 | Connector | XT30 Male/Female Pair × 3 | XT30 gold plated battery connectors | 1 | 3.00 | 3.00 | Amass / Amazon | XT30 pair | Search: XT30 connector pair | For battery leads and power distribution.
BOM-015 | Structure | Carbon Fibre Tube ø80mm OD × 320mm | CF tube – 80mm OD 76mm ID – 320mm length – plain weave | 1 | 14.00 | 14.00 | Hobbyking / DragonPlate / AliExpress | Search: CF tube 80mm OD | Search: carbon fibre tube 80mm | Cut to 320mm. Sand ends smooth. Main pod fuselage.
BOM-016 | Structure | PETG Filament 1kg – Black | 1.75mm PETG – 1kg spool – for all 3D printed structural parts | 0.5 | 22.00 | 11.00 | Prusament / Hatchbox / eSUN | PETG-175-BLK | prusa3d.com | Use PETG not PLA — better impact resistance and heat tolerance. 0.5kg estimate for all parts.
BOM-017 | Hardware | M3 Hex Bolts Assortment | M3 × 6/8/10/12/16mm bolts + nuts + washers stainless | 1 | 6.00 | 6.00 | Amazon / Local hardware |  | Search: M3 bolt assortment stainless | For servo mounts fin mounts and avionics tray.
BOM-018 | Hardware | M4 × 20mm Bolts + Nyloc Nuts × 4 | M4 bolts for wing saddle mounting | 1 | 2.00 | 2.00 | Amazon / Local hardware |  | Search: M4 bolts nyloc | Wing mount attachment bolts.
BOM-019 | Hardware | 1.5mm Music Wire (pushrods) – 500mm | Steel music wire for fin servo pushrods | 1 | 3.00 | 3.00 | Hobbyking / Local hobby shop |  | Search: 1.5mm music wire 500mm | Cut to length. Z-bend each end with pliers.
BOM-020 | Hardware | Du-Bro Micro E/Z Connectors × 8 | Pushrod end connectors for servo horns and fin horns | 1 | 4.00 | 4.00 | Du-Bro / Hobbyking | Du-Bro 845 | Search: dubro EZ connector micro | 2 per fin linkage × 4 fins = 8 total.
BOM-021 | Hardware | Vibration Dampening Foam Sheet 3mm | Neoprene foam for IMU isolation mount | 1 | 3.00 | 3.00 | Amazon |  | Search: vibration dampening foam 3mm | Cut to size under FC/IMU mount to isolate vibration.
BOM-022 | Hardware | Nylon Standoff M3 × 5mm × 8pcs | Nylon standoffs for FC and Pi mounting | 1 | 2.00 | 2.00 | Amazon |  | Search: nylon M3 standoff 5mm | Non-conductive. Do not use metal under FC — RF interference.
BOM-023 | Wire + Connectors | Silicone Wire 26AWG 1m each – 5 colours | Flexible silicone wire for all signal and power connections | 1 | 8.00 | 8.00 | Amazon |  | Search: 26AWG silicone wire 5 colour | Use 22AWG for high-current servo power rails.
BOM-024 | Wire + Connectors | JST-SH 1mm 4-pin Connector pairs × 5 | Micro connectors for sensor connections (GPS / IMU / Baro) | 1 | 5.00 | 5.00 | Adafruit / Amazon | #4328 | Search: JST-SH 1mm 4pin | For clean modular wiring.
BOM-025 | Wire + Connectors | Servo Extension 15cm × 5 | Male-female servo extension cables | 1 | 4.00 | 4.00 | Hobbyking / Amazon |  | Search: servo extension 15cm | Run from FC servo outputs to fin servos.
BOM-026 | Adhesives | 30-Minute Epoxy – 50ml syringe | Two-part structural epoxy for bonding 3D prints to CF tube | 1 | 6.00 | 6.00 | Loctite / Amazon | Loctite EA 3430 | Search: 30 minute epoxy structural | Do NOT use 5-minute epoxy for structural bonds. 30-min gives proper cure time.
BOM-027 | Adhesives | Thread-locking compound (Loctite 243) | Medium-strength thread locker for all servo and mount screws | 1 | 5.00 | 5.00 | Loctite |  | Loctite 243 blue | Apply to all servo mount M3 screws. Critical — vibration will loosen screws in flight.
BOM-028 | Finish | Spray Paint – Flat Black | Cosmetic finish for printed parts and CF tube | 1 | 4.00 | 4.00 | Local hardware |  | Any flat black rattle-can | Optional but reduces visual signature during testing.
BOM-029 | Target | Red Carpet 1m × 1m | Red short-pile carpet as optical target marker | 1 | 15.00 | 15.00 | Local home goods / Amazon |  | Search: red carpet 1m x 1m | Cut to exactly 1m² for known apparent size calculations.
BOM-030 | Target | Impact Cushion – Foam Block 60cm × 60cm × 30cm | High-density EVA or polyurethane foam cushion to absorb nose impact | 1 | 20.00 | 20.00 | Amazon / Local foam supplier |  | Search: EVA foam block 60x60x30 | Place ON TOP of red carpet. Pod impacts nose-first onto cushion. Min 30cm thick. High-density (firm) preferred.
BOM-031 | Tools | Servo Tester / Analyser | PWM servo tester for calibration and verification | 1 | 6.00 | 6.00 | Amazon |  | Search: servo tester digital | Essential for zeroing all 4 fin servos before first flight.
BOM-032 | Tools | LiPo Battery Charger | Balance charger compatible with 3S LiPo | 1 | 25.00 | 25.00 | ISDT / iCharger |  | Search: ISDT Q6 3S LiPo charger | Required for safe LiPo management.
 |  |  | TOTAL COMPONENT COST (excl. tools and carrier aircraft): |  | ~$265
 |  |  | NOTE: Carrier aircraft and RC transmitter/receiver pair not included in this BOM
 |  |  | NOTE: GCS laptop and Mission Planner software (free) not included

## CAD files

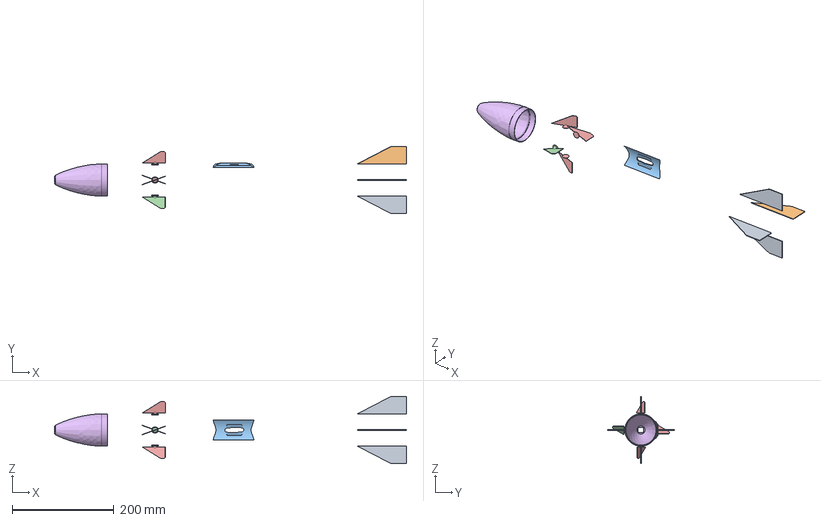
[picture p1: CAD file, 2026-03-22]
hardware/stl/droppod.step
692.0 x 132.5 x 132.5 mm

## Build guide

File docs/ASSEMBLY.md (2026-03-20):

# Assembly Guide
## Drop Pod — Step-by-Step Build

---

## Before You Start

- Read the **entire guide** before starting. Understand each step fully.
- Lay out all components and verify against [BOM.csv](../../BOM.csv).
- Print all 3D parts before starting (see [hardware/stl/README.md](../stl/README.md)).
- Have these tools ready:
  - Soldering iron + 63/37 solder
  - 30-minute epoxy
  - Loctite 243 (threadlocker)
  - M2, M3 hex key set
  - Digital multimeter
  - Servo tester
  - Pliers (for Z-bending pushrods)
  - 3.2mm drill bit (for screw hole cleanup)
  - 400-grit sandpaper

---

## Phase 1 — Camera Nose Assembly

The camera IS the nose of the pod. This is the first and most critical assembly step.

```
STEP 1.1 — Camera Module Preparation
  - Unbox RPi Camera Module 3 Wide
  - Handle by edges only — do not touch sensor or lens
  - Attach 200mm CSI-2 ribbon cable to camera (locking tab faces lens side)
  - Test camera on RPi before installing: rpicam-still -o test.jpg

STEP 1.2 — Nose Section Print Inspection
  - Inspect nose_camera_mount.stl for print defects
  - Camera pocket must be free of support material — clean with tweezers
  - Test-fit camera module in pocket. Should seat flush with lens at nose tip
  - If too tight: sand pocket with 400-grit, test-fit again
  - If too loose: add thin strip of foam tape around camera edges

STEP 1.3 — Camera Installation
  - Thread CSI ribbon through side slot in nose section FIRST
  - Lower camera module into pocket (lens facing nose tip)
  - Verify lens is flush or 0.5mm recessed from nose face
  - Apply thin bead of hot glue around 4 camera module edges
  - DO NOT get glue on lens or ribbon connector
  - Let cure 5 minutes before handling

STEP 1.4 — Nose-to-Tube Bond
  - Sand the front 20mm of CF tube OD with 120-grit for epoxy adhesion
  - Mix 30-minute epoxy, apply thin layer inside nose section socket
  - Press nose section onto CF tube front
  - Rotate nose section to align fin slots with subsequent fin mount slots
  - Hold or tape in position for 30 minutes minimum
  - Allow full cure: 24 hours before loads
```

---

## Phase 2 — Fin & Servo Assembly

```
STEP 2.1 — Servo Preparation
  - Test all 4 servos with servo tester BEFORE installing
  - Command each servo to 1500μs (neutral). Verify servo arm is at 90° to body
  - If arm is not at 90°, remove arm, reposition on spline, reinstall
  - Apply Loctite 243 to servo arm M2 screw

STEP 2.2 — Servo Installation in Fin Mount Ring
  - Press each servo into pocket in fin_mount_forward ring
  - Servo label should face inward (toward tube centre)
  - Secure each servo with M2×8 screws + Loctite 243
  - Servo orientation: arm swings toward tube centre when deflecting fin

STEP 2.3 — Pushrod Fabrication
  - Cut 4× 80mm lengths of 1.5mm music wire
  - Z-bend one end of each pushrod (90° bend, 5mm long leg)
  - Hook Z-bend into servo arm outermost hole
  - Other end: attach Du-Bro EZ connector

STEP 2.4 — Fin Installation
  - Slide fin_mount_forward assembly into CF tube from front
  - Position so fin slots align with the 4 pre-cut slots in tube
  - Secure with M3×12 screw through tube wall into ring (×2 per ring)
  - Slide fin blade root into slot, attach clevis to EZ connector
  - With servo at neutral (1500μs), fin should be perfectly flush with tube
  - If not: adjust EZ connector position on pushrod

STEP 2.5 — Full Deflection Test
  - Command each servo to 1200μs (full one way): verify fin deflects 20°
  - Command each servo to 1800μs (full other way): verify fin deflects 20°
  - Check for binding throughout travel
  - Verify fin snaps back to neutral when servo returns to 1500μs
```

---

## Phase 3 — Avionics Installation

```
STEP 3.1 — Avionics Tray Population
  - Solder nylon M3 standoffs to avionics_tray (4 per board)
  - Mount F405 FC at 30mm mark, using nylon standoffs
  - Mount vibration dampening foam pad between tray and FC
  - Mount RPi Zero 2W at 80mm mark, nylon standoffs

STEP 3.2 — GPS Installation
  - Mount u-blox M10 at 0mm mark (front of tray)
  - GPS patch antenna faces UP through hole in tray
  - Stick 15mm aluminium ground plane under antenna
  - Route UART cable to FC UART3

STEP 3.3 — Barometer
  - If using external BMP388: attach to I2C pads on FC or RPi
  - Drill 1mm vent hole in CF tube wall above sensor location
  - Cover vent hole with small foam square (static port foam)

STEP 3.4 — Tray Installation
  - Slide avionics tray into CF tube mid-section
  - Route CSI ribbon from nose section to RPi Camera connector
    CRITICAL: Connect CSI ribbon before closing tube. Cannot be done later.
  - Secure tray with M3×8 screws through tube wall

STEP 3.5 — ELRS Receiver
  - Mount ELRS receiver on tray with double-sided foam tape
  - Route antenna outside tube through small hole, tape along tube exterior
  - Connect SBUS wire to FC UART2 RX

STEP 3.6 — SiK Telemetry Radio
  - Mount SiK radio on tray rear section
  - Route antenna outside tube, position at 90° to ELRS antenna
  - Connect UART to FC UART4
```

---

## Phase 4 — Power Bay & Battery

```
STEP 4.1 — BEC Installation
  - Solder 22AWG leads from XT30 distribution board to both BEC inputs
  - BEC #1 output: 22AWG to FC 5V, RPi, GPS
  - BEC #2 output: 22AWG to servo power rail
  - Test each BEC output voltage before connecting any loads

STEP 4.2 — Battery Bay
  - Slide power_bay section onto CF tube rear
  - Route BEC input wires through power bay to battery cradle
  - Install XT30 female connector at rear of power bay
  - Secure power_bay with M3×8 screws

STEP 4.3 — Battery Test Install
  - Insert 3S LiPo — use Velcro straps to secure
  - Connect XT30 — verify system powers up
  - Check: FC boots (LED pattern), Pi boots (SSH in ~45s)

STEP 4.4 — Tail Cap
  - Install tail_ballast_cap with initial 50g steel weight
  - Secure with rubber O-ring or M3 screws
```

---

## Phase 5 — Carrier Aircraft Mount

```
STEP 5.1 — Saddle Mount Installation
  - Bolt wing_saddle_mount to carrier aircraft wing hardpoint
  - Use M4×20 bolts + nyloc nuts, torque to hand-tight + 1/4 turn
  - Verify mount is perpendicular to wing chord line (level check)

STEP 5.2 — Latch Servo
  - Mount release servo inside saddle mount housing
  - Fabricate retention pin from M3×25 steel bolt
  - Pin must pass through saddle mount wall and through pod saddle groove
  - Servo at 1500μs (neutral): pin is engaged (pod locked)
  - Servo at 2000μs (full): pin is retracted (pod free)

STEP 5.3 — Servo Extension Cable
  - Run servo extension from release servo to aircraft FC/receiver
  - Cable must have enough slack for wing flex without pulling servo
  - Secure cable with cable ties every 50mm along wing underside

STEP 5.4 — Pod Installation
  - Slide pod into saddle rail from rear
  - Push forward until pin engages in pod saddle groove (click)
  - Pull pod rearward lightly to confirm locked
  - Connect any inter-connection wires (power if pod battery on carrier)
```

---

## Phase 6 — Final Checks Before First Power-On

```
□ All M3 structural screws have Loctite 243
□ All soldered connections are visually inspected (no cold joints)
□ Multimeter continuity check: no shorts on 5V or servo rails
□ Battery XT30 polarity verified (XT30 is reverse-polarity-proof, but verify anyway)
□ CSI ribbon connector is fully seated at both ends (camera + Pi)
□ All servo signal connectors are correctly oriented (signal to correct pin)
□ GPS antenna not obstructed by metal parts
□ Pod CG is at 95–105mm from nose (see STL README for procedure)
□ All cable routing is secured and cannot contact servo linkages
□ Camera lens is clean and undamaged
```

---

## First Power-On Sequence

1. **Do not have pod mounted on aircraft for first power-on**
2. Connect battery XT30
3. Wait for FC to boot (ArduPlane splash screen on GCS)
4. Wait for RPi to boot (~45 seconds, SSH accessible)
5. Check GCS: all pre-arm checks green
6. Do **NOT** arm FC yet — just verify connectivity
7. Test all 4 servo outputs with servo test in Mission Planner
8. Verify fin deflection direction matches software mixer expectations
9. SSH into Pi, run: `python3 software/vision.py` — verify camera feed
10. Power down, correct any issues found
11. Ready for software configuration (see TUNING.md)

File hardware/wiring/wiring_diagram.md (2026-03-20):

# Wiring Diagram & Pinout Reference
## Drop Pod — Hardware Revision A

---

## Overview

The pod uses two power rails and three main communication buses:

| Bus | Protocol | Parties |
|-----|---|---|
| UART1 | MAVLink v2 @ 115200 | F405 FC ↔ RPi Zero 2W |
| UART2 | SBUS @ 100000 inv | ELRS Receiver → F405 FC |
| UART3 | MAVLink NMEA @ 38400 | u-blox GPS → F405 FC |
| SPI1 | SPI @ 8MHz | F405 FC → ICM-42688 IMU |
| I2C1 | I2C @ 400kHz | F405 FC → BMP388 Baro |
| CSI-2 | MIPI 2-lane | RPi Camera Module 3 → RPi Zero 2W |

---

## Power Architecture

```
3S LiPo (11.1V) ────────────── XT30 ─────────────────────────────
         │                                                        │
         ├── Pololu BEC #1 (5V / 2.2A) ──────────────────────────┤
         │   (Logic Rail)                                         │
         │   ├── F405 FC 5V input                                 │
         │   ├── RPi Zero 2W 5V (via GPIO pin 2 or USB-C)        │
         │   ├── u-blox GPS 5V                                    │
         │   └── SiK Radio 5V                                     │
         │                                                        │
         └── Pololu BEC #2 (5V / 2.2A) ──────────────────────────┤
             (Servo Rail)                                         │
             ├── Servo 1 (FIN TOP)    5V signal common           │
             ├── Servo 2 (FIN BOTTOM) 5V signal common           │
             ├── Servo 3 (FIN LEFT)   5V signal common           │
             ├── Servo 4 (FIN RIGHT)  5V signal common           │
             └── Servo 5 (LATCH)      5V signal common           │
                                                                  │
All GND ──────────────────────────────────────────────── GND ────┘
```

> ⚠️ **Critical**: The two BECs must share a common GND. Connect both BEC GND wires and the LiPo GND together. Never power servos from the same BEC as the FC/Pi — servo transients will reset/damage logic.

---

## Matek F405-WING Pinout

```
Matek F405-WING
┌─────────────────────────────────────┐
│ S1  ─────── FIN LEFT servo signal   │
│ S2  ─────── FIN RIGHT servo signal  │
│ S3  ─────── FIN TOP servo signal    │
│ S4  ─────── FIN BOTTOM servo signal │
│ S5  ─────── LATCH servo signal      │
│                                     │
│ UART1 TX ── RPi GPIO15 (RX)         │  MAVLink to companion
│ UART1 RX ── RPi GPIO14 (TX)         │
│ UART1 GND ─ RPi GND                 │
│                                     │
│ UART2 RX ── ELRS SBUS OUT           │  RC receiver (inverted SBUS)
│                                     │
│ UART3 TX ── GPS RX                  │  u-blox GPS
│ UART3 RX ── GPS TX                  │
│                                     │
│ SPI SCK  ── ICM-42688 SCK           │  External IMU (if not using onboard)
│ SPI MOSI ── ICM-42688 SDI           │
│ SPI MISO ── ICM-42688 SDO           │
│ CS1      ── ICM-42688 CS            │
│                                     │
│ I2C SCL  ── BMP388 SCL              │  Barometer
│ I2C SDA  ── BMP388 SDA              │
│                                     │
│ UART4 TX ── SiK Radio RX            │  Telemetry to GCS
│ UART4 RX ── SiK Radio TX            │
│                                     │
│ BAT+     ── LiPo V+ (voltage sense) │
│ GND      ── Common GND              │
│ 5V in    ── BEC #1 5V output        │
│ VCC servo── BEC #2 5V output        │
└─────────────────────────────────────┘
```

---

## Raspberry Pi Zero 2W Pinout

```
RPi Zero 2W — 40-Pin Header
┌───────────┬─────┬─────┬──────────────┐
│ Function  │ Pin │ Pin │ Function     │
├───────────┼─────┼─────┼──────────────┤
│ 3.3V      │  1  │  2  │ 5V           │ ← 5V from BEC #1
│ GPIO2 SDA │  3  │  4  │ 5V           │
│ GPIO3 SCL │  5  │  6  │ GND          │ ← Common GND
│ GPIO4     │  7  │  8  │ GPIO14 (TX)  │ ← UART0 TX → FC UART1 RX
│ GND       │  9  │ 10  │ GPIO15 (RX)  │ ← UART0 RX ← FC UART1 TX
│ ...       │ ... │ ... │ ...          │
└───────────┴─────┴─────┴──────────────┘

CSI Camera Port (bottom of board):
  ← RPi Camera Module 3 Wide (15-pin FFC ribbon cable)
  Ensure camera orientation: lens faces NOSE DIRECTION
  (forward/downward during pod descent)
```

**RPi UART Setup:**
```bash
# In /boot/config.txt:
enable_uart=1
dtoverlay=disable-bt   # Free up UART0 (disable Bluetooth)

# In /boot/cmdline.txt — remove:
# console=serial0,115200
```

---

## u-blox M10 GPS

```
u-blox M10 Breakout
┌─────────────────┐
│ VCC ─── 5V      │ ← BEC #1 5V
│ GND ─── GND     │
│ TX  ─── FC UART3 RX  │
│ RX  ─── FC UART3 TX  │
│ PPS ─── FC GPIO (optional, for time sync) │
│ Antenna: patch antenna facing UP in nose section │
└─────────────────┘
```

GPS Antenna Placement:
- Mount patch antenna flat, facing skyward (top of pod)
- 15mm aluminium ground plane behind antenna improves gain
- Keep at least 30mm away from any servos or high-current wires

---

## ELRS Receiver (e.g. BetaFPV ELRS Lite)

```
ELRS Receiver
┌──────────────┐
│ 5V  ── 5V    │ ← BEC #1
│ GND ── GND   │
│ SBUS─── FC UART2 RX (set SERIAL2_PROTOCOL = 23 for SBUS) │
└──────────────┘
```

> **Note**: SBUS is an inverted serial signal. Most ArduPlane FC boards auto-detect this. If not, use a hardware inverter (single NPN transistor circuit).

---

## SiK 915MHz Telemetry Radio

```
SiK Radio (Pod unit)
┌──────────────┐
│ 5V  ── 5V    │ ← BEC #1
│ GND ── GND   │
│ TX  ── FC UART4 RX  │
│ RX  ── FC UART4 TX  │
└──────────────┘

SiK Radio (GCS unit) → USB to laptop
Configure both radios with SiK firmware at same baud (57600)
Net ID must match between pair.
```

---

## Latch Servo (on Carrier Aircraft Wing)

```
CARRIER AIRCRAFT WING
┌─────────────────────────────────────┐
│ Release servo (9g)                  │
│   Signal ── FC S5 output            │ ← Long servo extension cable runs
│   5V     ── BEC #2 5V               │   from pod to wing mount point
│   GND    ── GND                     │
│                                     │
│ Retention pin: M3 × 20mm steel bolt │
│ Servo pulls: 8mm stroke to clear pin│
└─────────────────────────────────────┘

At PWM 1500μs (TRIM) → pin engaged, pod locked
At PWM 2000μs (MAX)  → pin retracted, pod released
```

---

## ICM-42688-P IMU (External, if FC onboard IMU is insufficient)

```
ICM-42688-P Breakout
┌──────────────┐
│ VCC ── 3.3V  │ ← FC 3.3V out
│ GND ── GND   │
│ SCK ── SPI SCK  │
│ SDI ── SPI MOSI │
│ SDO ── SPI MISO │
│ CS  ── SPI CS1  │
│ INT ── FC GPIO (optional interrupt) │
└──────────────┘

Mount on 3mm vibration dampening foam under FC.
Align axes: X = forward (toward nose), Y = right, Z = down.
```

---

## BMP388 Barometer

```
BMP388 Breakout
┌──────────────┐
│ VCC ── 3.3V  │
│ GND ── GND   │
│ SCL ── I2C SCL  │
│ SDA ── I2C SDA  │
└──────────────┘

Important: Place in a vented enclosure or expose to ambient air.
If sealed in fuselage, drill 1mm vent holes near sensor.
Cover vent holes with foam to block wind.
```

---

## Wire Gauge Recommendations

| Connection | Wire Gauge | Reason |
|---|---|---|
| LiPo to BEC inputs | 22 AWG | Up to 3A continuous |
| BEC outputs to FC/Pi | 26 AWG | Low current logic |
| BEC #2 to servo common rail | 22 AWG | Peak servo current |
| Servo signal wires | 26 AWG | Signal only |
| GPS / Baro / IMU | 26 AWG silicone | Flexible signal |

Use **silicone-insulated** wire throughout — it remains flexible at low temperatures and resists vibration cracking.

---

## Wiring Checklist Before First Power-On

```
□ Both BEC input voltages correct (11.1V from LiPo)
□ Both BEC output voltages measured: 5.0V ± 0.1V
□ FC 5V rail measured: 5.0V ± 0.1V  
□ RPi 5V measured at GPIO pin 2: 5.0V ± 0.1V
□ All GND connections are continuous (test with multimeter)
□ No shorts between 5V rails and GND
□ No shorts between BEC #1 and BEC #2 output rails
□ Servo signal wires connected to correct FC output pins
□ UART wires: TX→RX and RX→TX (crossed correctly)
□ Camera ribbon cable seated fully in both connectors
□ GPS antenna facing upward, away from metal
□ All connectors hot-glued or zip-tied for vibration security
```

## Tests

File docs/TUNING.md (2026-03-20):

# PID Tuning Guide
## Drop Pod — Control System Calibration

---

## Philosophy

**Never tune on a real drop from altitude before completing all lower-risk steps.**

Follow this progression:

```
Level 0: Bench test (no flight, no movement)
Level 1: Hand-drop from 1–2m
Level 2: Drop from pole/crane at 10–20m
Level 3: Full aircraft drop at 60–100m
```

Only move to the next level when the current level is fully verified.

---

## Level 0 — Bench Tests

### 0.1 Servo Zero Calibration

Before ANY tuning, all fins must be perfectly zeroed:

```bash
# In Mission Planner:
# Config → Servo Output → Test
# Set each servo (S1–S4) to 1500μs
# Each fin should be FLUSH with the tube body
# If not flush: adjust servo arm position on spline
```

Acceptable tolerance: ±0.5° from flush. Any more and you'll have a persistent roll/pitch offset.

### 0.2 Fin Deflection Direction

Run this test and compare to expected:

| Servo command | Expected fin deflection | Expected pod response |
|---|---|---|
| S3 = 1700μs (FIN TOP up) | Top fin deflects left (into airstream) | Pitch nose up |
| S3 = 1300μs (FIN TOP down) | Top fin deflects right | Pitch nose down |
| S4 = 1700μs (FIN BOTTOM) | Bottom fin deflects opposite to top | Pitch nose up (same as top) |
| S1 = 1700μs (FIN LEFT up) | Left fin deflects | Roll right |
| S2 = 1700μs (FIN RIGHT) | Right fin deflects opposite to left | Roll right (same) |

If any fin moves the wrong way: set `SERVOx_REVERSED = 1` for that servo in ArduPlane params.

### 0.3 Control Mixing Verification

In ArduPlane, roll pilot input should move S1+S2 differentially.
Pitch pilot input should move S3+S4 symmetrically.

Test with TX in MANUAL mode:
- Pitch stick forward: both FIN TOP and FIN BOTTOM deflect to pitch nose down
- Roll stick right: FIN LEFT and FIN RIGHT deflect differentially to roll right

### 0.4 IMU Axis Verification

Mount pod on flat surface. Check GCS:
- Roll = 0°, Pitch = 0°, Yaw = any value ✓
- Tilt nose up 30°: Pitch shows +30° ✓
- Roll right 30°: Roll shows +30° ✓

If any axis is inverted or swapped: check AHRS_ORIENTATION param in ArduPlane.

---

## Level 1 — Hand Drop Tests (1–2m height)

### 1.1 Attitude Stabilisation Test

Hold pod horizontally, tip nose down 20°, then release:
- Pod should correct back toward level attitude within 1–2 seconds
- If it oscillates wildly: reduce `RLL_RATE_P` and `PTCH_RATE_P` by 20%
- If it barely corrects: increase P gains by 20%

### 1.2 Step Response Tuning

With pod in hand (simulate holding it during descent), command roll input:
- Response should be: fast initial movement, no overshoot, settles quickly
- Oscillation = too much P or too little D
- Sluggish = not enough P
- Steady-state error = not enough I

### 1.3 Starting PID Values

Use these as the initial starting point:

```
# Pitch Rate Loop
PTCH_RATE_P = 0.08
PTCH_RATE_I = 0.020  
PTCH_RATE_D = 0.004
PTCH_RATE_FF = 0.0

# Pitch Angle Loop  
PTCH2SRV_P = 1.5
PTCH2SRV_I = 0.2
PTCH2SRV_D = 0.04

# Roll Rate Loop
RLL_RATE_P = 0.10
RLL_RATE_I = 0.020
RLL_RATE_D = 0.004

# Roll Angle Loop
RLL2SRV_P = 1.8
RLL2SRV_I = 0.2
RLL2SRV_D = 0.04
```

---

## Level 2 — Low-Altitude Drops (10–20m)

Use a tall ladder, crane, or first-floor window ledge. Drop pod by hand.

### 2.1 What to Observe

1. **Separation stability**: does pod immediately stabilise? Should be level within 0.5s
2. **Directional bias**: does pod consistently drift left/right or nose up/down?
3. **Oscillation**: does pod "wag" or "hunt" during descent?
4. **GPS tracking**: does pod turn toward the target waypoint?

### 2.2 Common Issues and Fixes

| Symptom | Likely Cause | Fix |
|---|---|-----|
| Rolls immediately on release | Servo zero offset | Re-zero all servos |
| Pitches nose-up consistently | CG too far back | Move battery forward |
| High-frequency oscillation | Too much D or P | Reduce D first, then P by 10% |
| Slow response to roll commands | Too little P | Increase RLL_RATE_P by 15% |
| Oscillates and diverges | Unstable (too much P) | Reduce P gains 30%, restart |
| No GPS correction | Wrong mode or WP not set | Check GUIDED mode, verify WP set |

### 2.3 Tuning Procedure (Ziegler-Nichols Simplified)

For each axis independently:
1. Set I and D to zero
2. Increase P until steady oscillation appears (critical gain Kc)
3. Record oscillation period Tc
4. Set: P = 0.6×Kc, I = 1.2×Kc/Tc, D = 0.075×Kc×Tc
5. Reduce all by 20% for safety margin

---

## Level 3 — Full Altitude Drops (60m+)

Only proceed here when Level 2 shows stable, well-damped attitude control.

### 3.1 First Full Drop Protocol

- Start at 60m AGL (minimum)
- Target offset: 50m horizontal (conservative)
- Camera threshold: 40m AGL
- Observe via GCS: track pod state transitions

### 3.2 Vision System Tuning

If camera locks poorly:

```python
# In config.py — adjust HSV thresholds:
# Make red detection more permissive if missing carpet:
HSV_RED_LOW_1  = (0,  100, 60)   # Lower S and V thresholds
HSV_RED_HIGH_1 = (15, 255, 255)  # Wider hue range

# Make more restrictive if getting false positives (other red objects):
HSV_RED_LOW_1  = (0,  150, 100)  # Higher saturation required
HSV_RED_HIGH_1 = (10, 255, 255)  # Narrower hue range
```

Run `python3 software/vision.py` on ground with the carpet lit by the same lighting conditions expected in field to tune thresholds before flight.

### 3.3 Optical Gain Tuning

```python
# In config.py:
# If pod overshoots target during optical phase (oscillates around target):
KV_LATERAL = 0.25  # Reduce from 0.4

# If pod doesn't track fast enough:
KV_LATERAL = 0.5   # Increase from 0.4

# Pitch correction should almost always be smaller than lateral:
KV_PITCH = 0.10    # Further reduce if any instability appears
```

### 3.4 Accuracy Evaluation

After each drop:
1. Measure distance from pod nose-impact to carpet centre
2. Log: drop altitude, wind speed, measured landing error, direction of error
3. Build a correction table across altitudes

| Drop Altitude | Wind | Expected CEP | Notes |
|---|---|---|---|
| 60m | <2 m/s | ≤ 2m | Optical phase dominant |
| 100m | <2 m/s | ≤ 3m | GPS phase longer |
| 60m | 5 m/s | ≤ 5m | Wind compensation |

---

## L1 Navigation Tuning

The L1 controller governs how aggressively the pod turns toward the target during GPS phase.

```
NAVL1_PERIOD (default: 18)
  - Lower = more aggressive tracking, tighter turns
  - Higher = smoother, more gentle arcs
  - For pod descent (fast, no loitering): 12–16 is appropriate
  
NAVL1_DAMPING (default: 0.75)
  - Lower = more oscillation around track
  - Higher = overdamped, sluggish
  - Typically leave at 0.75
```

---

## Log Analysis

Every flight generates ArduPlane logs (.bin) on the FC SD card.

Download and analyse with Mission Planner → DataFlash Log → Review:
- **ATT**: Actual vs desired attitude (RollIn vs Roll, PitchIn vs Pitch)
- **GPS**: Position accuracy, HDOP
- **RCIN**: RC channel inputs (verify ARM/DROP on correct channels)
- **MODE**: Flight mode changes (should see AUTO or GUIDED during descent)

Key signature of well-tuned system:
```
ATT.RollIn ≈ ATT.Roll  (small error, no oscillation)
ATT.PitchIn ≈ ATT.Pitch (small error, no oscillation)
GPS tracking: smooth approach to WP, not hunting
```

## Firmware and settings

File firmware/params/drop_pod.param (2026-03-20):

# Drop Pod — ArduPlane Parameter File
# Load via Mission Planner: Full Param List → Load from file
#
# Based on ArduPlane 4.4+
# Hardware: Matek H743-WING or F405-WING
# Mode: Fixed-wing glider (no throttle, no propulsion)
#
# IMPORTANT: After loading, ALWAYS recalibrate:
# 1. Accelerometer (6-point)
# 2. Compass
# 3. Radio/RC
# 4. ESC (not needed — no motor)
# Then do servo test to verify fin deflection directions.

# ── FRAME TYPE ────────────────────────────────────────────
FRAME_CLASS,2                   # Fixed wing
FRAME_TYPE,1                    # Conventional

# ── INITIAL FLIGHT MODE ───────────────────────────────────
INITIAL_MODE,0                  # Manual on startup (safe)
FLTMODE1,0                      # Manual
FLTMODE2,5                      # FBWA (Fly-By-Wire A) — good for test
FLTMODE3,10                     # Auto — for GPS guided flight
FLTMODE4,4                      # Guided — for dynamic waypoint
FLTMODE5,0                      # Manual (emergency)
FLTMODE6,0

# ── SERVO OUTPUT ASSIGNMENTS ──────────────────────────────
# Canard fin layout: cruciform, 4 fins at nose
# Mix: Fin TOP = elevator-like (pitch), L/R = aileron-like (roll)
SERVO1_FUNCTION,4               # Aileron (maps to FIN LEFT)
SERVO2_FUNCTION,4               # Aileron reversed (FIN RIGHT)
SERVO3_FUNCTION,19              # Elevator (FIN TOP)
SERVO4_FUNCTION,19              # Elevator reversed (FIN BOTTOM)
SERVO5_FUNCTION,28              # Relay 1 (latch servo — CH5)

# Servo direction — adjust if fin deflects wrong way
SERVO1_REVERSED,0
SERVO2_REVERSED,1               # Typically needs reversal for opposite fin
SERVO3_REVERSED,0
SERVO4_REVERSED,1
SERVO5_REVERSED,0

# Servo travel limits (microseconds)
SERVO1_MIN,1000
SERVO1_MAX,2000
SERVO1_TRIM,1500
SERVO2_MIN,1000
SERVO2_MAX,2000
SERVO2_TRIM,1500
SERVO3_MIN,1000
SERVO3_MAX,2000
SERVO3_TRIM,1500
SERVO4_MIN,1000
SERVO4_MAX,2000
SERVO4_TRIM,1500
SERVO5_MIN,1000
SERVO5_MAX,2000
SERVO5_TRIM,1500                # Latch: 1500=locked, 2000=released

# ── CONTROL SURFACE LIMITS ────────────────────────────────
LIM_ROLL_CD,3500                # Max roll 35° (3500 centidegrees)
LIM_PITCH_MAX,2000              # Max pitch up 20°
LIM_PITCH_MIN,-3000             # Max pitch down 30°

# ── RC CHANNEL ASSIGNMENTS ────────────────────────────────
RCMAP_ROLL,1
RCMAP_PITCH,2
RCMAP_THROTTLE,3
RCMAP_YAW,4
# CH5 = Flight mode switch
# CH7 = ARM command (mission manager reads via MAVLink)
# CH8 = DROP command
# CH9 = ABORT command

# ── RC FAILSAFE ───────────────────────────────────────────
FS_SHORT_ACTN,0                 # Short failsafe: continue
FS_LONG_ACTN,1                  # Long failsafe: FBWA mode
FS_GCS_ENABL,1                  # Enable GCS failsafe
FS_GCS_TIMEOUT,5                # GCS timeout seconds

# ── ATTITUDE CONTROL PID (Pitch) ──────────────────────────
# These are starting values — tune per hardware
PTCH_RATE_P,0.08
PTCH_RATE_I,0.02
PTCH_RATE_D,0.004
PTCH_RATE_FF,0.0
PTCH_RATE_IMAX,0.25
PTCH2SRV_P,1.5
PTCH2SRV_I,0.2
PTCH2SRV_D,0.04
PTCH2SRV_IMAX,3000

# ── ATTITUDE CONTROL PID (Roll) ───────────────────────────
RLL_RATE_P,0.10
RLL_RATE_I,0.02
RLL_RATE_D,0.004
RLL_RATE_FF,0.0
RLL_RATE_IMAX,0.25
RLL2SRV_P,1.8
RLL2SRV_I,0.2
RLL2SRV_D,0.04
RLL2SRV_IMAX,3000

# ── NAVIGATION (L1 Controller) ────────────────────────────
NAVL1_PERIOD,18                 # L1 period — lower = more aggressive tracking
NAVL1_DAMPING,0.75

# ── TECS (Glide Energy Management) ───────────────────────
# No throttle — TECS manages pitch only to maintain speed/sink
TECS_CLMB_MAX,0.0               # No climb — we only descend
TECS_SINK_MIN,1.0               # Minimum sink rate (m/s)
TECS_SINK_MAX,6.0               # Max sink rate — nose-impact mode
TECS_TIME_CONST,5.0
TECS_THR_DAMP,0.1
TECS_PTCH_DAMP,0.3
ARSPD_FBW_MIN,10                # Min airspeed 10 m/s
ARSPD_FBW_MAX,22                # Max airspeed 22 m/s
TRIM_ARSPD_CM,1400              # Trim airspeed 14 m/s

# Disable throttle entirely (no propulsion)
THR_MAX,0
THR_MIN,0
THR_TRIM,0

# ── EKF CONFIGURATION ─────────────────────────────────────
EK3_ENABLE,1
EK2_ENABLE,0                    # Use EKF3 only
EK3_GPS_TYPE,0                  # Use GPS for position and velocity
EK3_SRC1_POSXY,3                # GPS for horizontal position
EK3_SRC1_VELXY,3                # GPS for horizontal velocity
EK3_SRC1_POSZ,1                 # Baro for vertical position
EK3_SRC1_VELZ,0

# ── GPS ───────────────────────────────────────────────────
GPS_TYPE,1                      # u-blox
GPS_NAVFILTER,8                 # Most accurate filter
GPS_AUTO_CONFIG,1               # Auto-configure u-blox
GPS_MIN_ELEV,5                  # Min satellite elevation 5°
GPS_HDOP_GOOD,140               # HDOP threshold for "good" fix

# ── BAROMETER ─────────────────────────────────────────────
BARO_PROBE_EXT,1                # Enable external baro (BMP388)

# ── COMPANION COMPUTER (RPi) ──────────────────────────────
SERIAL1_PROTOCOL,2              # MAVLink2 on UART1 (connected to Pi)
SERIAL1_BAUD,115                # 115200 baud
SYSID_MYGCS,255                 # GCS sysid
SYSID_THISMAV,1                 # FC sysid

# ── RELAY (Latch Servo) ───────────────────────────────────
RELAY_PIN,13                    # GPIO13 → maps to SERVO5 output
RELAY_PIN2,-1
RELAY_DEFAULT,0                 # Default: latch CLOSED on boot

# ── ARMING CHECKS ─────────────────────────────────────────
ARMING_CHECK,1                  # All checks enabled
ARMING_REQUIRE,1                # Require arming before any output

# ── LOGGING ───────────────────────────────────────────────
LOG_BITMASK,65535               # Log everything
LOG_DISARMED,1                  # Log even when disarmed (useful for testing)

# ── MISC ──────────────────────────────────────────────────
WP_RADIUS,5                     # Waypoint capture radius 5m
WP_LOITER_RAD,20                # Loiter radius (not normally used)
STAB_PITCH_DOWN,2               # Auto-pitch down when no throttle (glide assist)

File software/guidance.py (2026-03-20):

"""
guidance.py — Reachability Check & Optical Correction
======================================================
Computes whether the target is reachable from the current
pod position and altitude, and converts camera centroid
error into roll/pitch correction angles for the FC.
"""

import math
import logging
from dataclasses import dataclass

import config

log = logging.getLogger("GUIDANCE")


# ──────────────────────────────────────────────────────────────────
# CONSTANTS
# ──────────────────────────────────────────────────────────────────

EARTH_RADIUS_M = 6_371_000.0  # Earth mean radius in metres


# ──────────────────────────────────────────────────────────────────
# DATA STRUCTURES
# ──────────────────────────────────────────────────────────────────

@dataclass
class OpticalCorrection:
    """Angular corrections derived from camera centroid error."""
    roll_deg:  float   # Positive = roll right
    pitch_deg: float   # Positive = pitch up (nose up)
    err_x_norm: float  # Normalised lateral error (-1.0 to +1.0)
    err_y_norm: float  # Normalised longitudinal error (-1.0 to +1.0)


# ──────────────────────────────────────────────────────────────────
# GREAT-CIRCLE DISTANCE
# ──────────────────────────────────────────────────────────────────

def haversine_distance(lat1: float, lon1: float,
                        lat2: float, lon2: float) -> float:
    """
    Compute the great-circle distance between two GPS points.

    Args:
        lat1, lon1: Source point (decimal degrees)
        lat2, lon2: Destination point (decimal degrees)

    Returns:
        Distance in metres.
    """
    phi1   = math.radians(lat1)
    phi2   = math.radians(lat2)
    dphi   = math.radians(lat2 - lat1)
    dlambda= math.radians(lon2 - lon1)

    a = (math.sin(dphi   / 2) ** 2 +
         math.cos(phi1) * math.cos(phi2) *
         math.sin(dlambda / 2) ** 2)

    c = 2 * math.atan2(math.sqrt(a), math.sqrt(1 - a))
    return EARTH_RADIUS_M * c


def bearing_to(lat1: float, lon1: float,
               lat2: float, lon2: float) -> float:
    """
    Initial bearing from point 1 to point 2.

    Returns:
        Bearing in degrees (0 = North, 90 = East).
    """
    phi1    = math.radians(lat1)
    phi2    = math.radians(lat2)
    dlambda = math.radians(lon2 - lon1)

    x = math.sin(dlambda) * math.cos(phi2)
    y = (math.cos(phi1) * math.sin(phi2) -
         math.sin(phi1) * math.cos(phi2) * math.cos(dlambda))

    brng = math.degrees(math.atan2(x, y))
    return (brng + 360) % 360


# ──────────────────────────────────────────────────────────────────
# REACHABILITY CHECKER
# ──────────────────────────────────────────────────────────────────

class ReachabilityChecker:
    """
    Determines whether the target is within glide range of the pod.

    The check is:
        reachable if: distance_to_target ≤ (alt_agl × glide_ratio × safety_margin)

    A safety margin is applied to the theoretical max range so we
    never arrive at the target with exactly zero altitude margin.
    """

    def __init__(self,
                 glide_ratio: float   = config.GLIDE_RATIO,
                 safety_margin: float = config.SAFETY_MARGIN):
        self.glide_ratio    = glide_ratio
        self.safety_margin  = safety_margin

    def check(self,
              pod_lat: float,  pod_lon: float,
              pod_alt_agl: float,
              target_lat: float, target_lon: float,
              ) -> tuple[bool, float, float]:
        """
        Perform the reachability check.

        Args:
            pod_lat, pod_lon:       Pod GPS coordinates (decimal degrees)
            pod_alt_agl:            Pod altitude above ground level (metres)
            target_lat, target_lon: Target GPS coordinates (decimal degrees)

        Returns:
            Tuple of:
                reachable (bool):       True if target is within glide range
                distance_m (float):     Horizontal distance to target (metres)
                max_range_m (float):    Maximum reachable range from this altitude
        """
        distance_m  = haversine_distance(pod_lat, pod_lon, target_lat, target_lon)
        max_range_m = pod_alt_agl * self.glide_ratio * self.safety_margin

        reachable = distance_m <= max_range_m

        log.debug(
            "Reachability: dist=%.1fm  max=%.1fm  ratio=%.2f  → %s",
            distance_m, max_range_m,
            distance_m / max_range_m if max_range_m > 0 else float('inf'),
            "IN RANGE" if reachable else "OUT OF RANGE"
        )

        return reachable, distance_m, max_range_m

    def utilisation(self, pod_lat, pod_lon, pod_alt_agl,
                    target_lat, target_lon) -> float:
        """
        Returns the fraction of maximum range currently used.
        0.0 = at target, 1.0 = exactly at edge of range,
        > 1.0 = out of range.
        """
        _, dist, max_r = self.check(pod_lat, pod_lon, pod_alt_agl,
                                    target_lat, target_lon)
        return dist / max_r if max_r > 0 else float('inf')


# ──────────────────────────────────────────────────────────────────
# OPTICAL GUIDANCE CORRECTION
# ──────────────────────────────────────────────────────────────────

def compute_optical_correction(cx: float, cy: float,
                                frame_w: int, frame_h: int,
                                ) -> OpticalCorrection:
    """
    Convert camera centroid pixel error to roll/pitch correction angles.

    The camera is nose-mounted and faces the direction of travel.
    As the pod descends toward the target:
    - Lateral error (cx != frame centre) → roll correction
    - Longitudinal error (cy != frame centre) → pitch correction

    The corrections are ADDITIVE biases injected into the FC
    attitude setpoints, not absolute commands.

    Args:
        cx, cy:         Detected centroid position (pixels)
        frame_w, frame_h: Frame dimensions (pixels)

    Returns:
        OpticalCorrection with roll_deg and pitch_deg correction
    """
    # Normalise error to [-1.0, +1.0]
    # Positive err_x = target is to the RIGHT of frame centre
    # Positive err_y = target is BELOW frame centre (closer in dive)
    err_x = (cx - frame_w / 2.0) / (frame_w / 2.0)
    err_y = (cy - frame_h / 2.0) / (frame_h / 2.0)

    # Convert to angular corrections using FOV scaling
    # Half-FOV gives the maximum angular span at the frame edge
    half_fov_h = config.CAM_FOV_H_DEG / 2.0
    half_fov_v = config.CAM_FOV_V_DEG / 2.0

    ang_x = err_x * half_fov_h  # degrees
    ang_y = err_y * half_fov_v  # degrees

    # Apply guidance gains
    roll_cmd  = ang_x * config.KV_LATERAL
    pitch_cmd = ang_y * config.KV_PITCH

    # Safety clamp — never command more than max correction
    max_c = config.MAX_OPTICAL_CORRECTION_DEG
    roll_cmd  = max(-max_c, min(max_c, roll_cmd))
    pitch_cmd = max(-max_c, min(max_c, pitch_cmd))

    return OpticalCorrection(
        roll_deg=roll_cmd,
        pitch_deg=pitch_cmd,
        err_x_norm=err_x,
        err_y_norm=err_y,
    )


# ──────────────────────────────────────────────────────────────────
# FLIGHT PATH ANGLE
# ──────────────────────────────────────────────────────────────────

def required_flight_path_angle(distance_m: float, alt_agl_m: float) -> float:
    """
    Compute the required Flight Path Angle (FPA) to reach a target
    at a given horizontal distance and current altitude.

    Args:
        distance_m: Horizontal distance to target (metres)
        alt_agl_m:  Current altitude above ground (metres)

    Returns:
        FPA in degrees. Negative = nose down (descending toward target).
    """
    if distance_m <= 0:
        return -90.0  # Directly overhead — dive straight down
    return -math.degrees(math.atan2(alt_agl_m, distance_m))


# ──────────────────────────────────────────────────────────────────
# SELF-TEST
# ──────────────────────────────────────────────────────────────────

if __name__ == "__main__":
    logging.basicConfig(level=logging.DEBUG)

    checker = ReachabilityChecker()

    print("=== REACHABILITY CHECK TESTS ===")

    # Test 1: Should be reachable (100m alt → ~340m max range at 4:1 ratio × 0.85)
    r, d, m = checker.check(33.5731, -7.5898, 100.0, 33.5750, -7.5898)
    print(f"Test 1 (nearby, 100m): reachable={r}, dist={d:.0f}m, max={m:.0f}m")
    assert r is True, "Should be reachable"

    # Test 2: Should NOT be reachable (10m alt → ~34m max range)
    r, d, m = checker.check(33.5731, -7.5898, 10.0, 33.5750, -7.5898)
    print(f"Test 2 (far, low alt): reachable={r}, dist={d:.0f}m, max={m:.0f}m")
    assert r is False, "Should NOT be reachable"

    print("\n=== OPTICAL CORRECTION TESTS ===")

    # Target perfectly centred
    c = compute_optical_correction(640, 360, 1280, 720)
    print(f"Centred: roll={c.roll_deg:.2f}° pitch={c.pitch_deg:.2f}°")
    assert abs(c.roll_deg) < 0.01 and abs(c.pitch_deg) < 0.01

    # Target top-right of frame
    c = compute_optical_correction(960, 180, 1280, 720)
    print(f"Top-right: roll={c.roll_deg:+.2f}° pitch={c.pitch_deg:+.2f}°")
    assert c.roll_deg > 0   # Roll right
    assert c.pitch_deg < 0  # Pitch down (target above centre)

    print("\nAll tests passed ✓")

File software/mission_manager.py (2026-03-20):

"""
mission_manager.py — Drop Pod Mission State Machine
=====================================================
Main entry point. Runs on Raspberry Pi Zero 2W.
Manages high-level mission phases, communicates with
the F405 flight controller via MAVLink, and triggers
the vision pipeline at the correct altitude.

Run: python3 mission_manager.py
"""

import asyncio
import logging
import time
import signal
import sys
from enum import Enum, auto
from dataclasses import dataclass, field
from typing import Optional

import config
from comms import FC_Link
from vision import RedCarpetTracker
from guidance import ReachabilityChecker, compute_optical_correction

# ──────────────────────────────────────────────────────────────────
# LOGGING SETUP
# ──────────────────────────────────────────────────────────────────

logging.basicConfig(
    level=getattr(logging, config.LOG_LEVEL),
    format="%(asctime)s [%(levelname)-8s] %(name)s: %(message)s",
    handlers=[
        logging.StreamHandler(sys.stdout),
        logging.FileHandler(f"{config.LOG_DIR}/mission_{int(time.time())}.log"),
    ]
)
log = logging.getLogger("MISSION")


# ──────────────────────────────────────────────────────────────────
# MISSION STATES
# ──────────────────────────────────────────────────────────────────

class MissionState(Enum):
    IDLE         = auto()   # Pre-arm, passive on carrier wing
    ARMED        = auto()   # ARM received, monitoring, latch ready
    RELEASED     = auto()   # Latch fired, pod in free flight
    GLIDE_GPS    = auto()   # GPS-guided approach toward target
    GLIDE_OPTICAL= auto()   # Camera locked, optical terminal guidance
    LANDED       = auto()   # Impact detected, mission complete
    ABORT        = auto()   # Operator abort or safety fault


# ──────────────────────────────────────────────────────────────────
# TELEMETRY SNAPSHOT (thread-safe shared state)
# ──────────────────────────────────────────────────────────────────

@dataclass
class PodTelemetry:
    """Current pod state, updated by FC MAVLink messages."""
    lat: float          = 0.0
    lon: float          = 0.0
    alt_msl: float      = 0.0
    alt_agl: float      = 0.0
    roll_deg: float     = 0.0
    pitch_deg: float    = 0.0
    yaw_deg: float      = 0.0
    vx: float           = 0.0   # velocity m/s
    vy: float           = 0.0
    vz: float           = 0.0
    gps_fix: bool       = False
    gps_hdop: float     = 99.0
    battery_v: float    = 0.0
    battery_pct: float  = 0.0
    accel_g: float      = 0.0
    rc_arm_high: bool   = False
    rc_drop_high: bool  = False
    rc_abort_high: bool = False
    timestamp: float    = field(default_factory=time.time)


# ──────────────────────────────────────────────────────────────────
# MISSION MANAGER
# ──────────────────────────────────────────────────────────────────

class MissionManager:
    def __init__(self):
        self.state = MissionState.IDLE
        self.telemetry = PodTelemetry()
        self.mission_start_time: Optional[float] = None
        self.drop_time: Optional[float] = None
        self._running = True

        # Sub-systems (initialised in run())
        self.fc: Optional[FC_Link] = None
        self.tracker: Optional[RedCarpetTracker] = None
        self.reachability: Optional[ReachabilityChecker] = None

        # Tracking state
        self.lock_frame_count = 0
        self.camera_active = False

        log.info("MissionManager initialised. State: IDLE")

    # ────────────────────────────────────────────────────────────
    # MAIN LOOP
    # ────────────────────────────────────────────────────────────

    async def run(self):
        """Main async mission loop. Entry point."""
        log.info("Starting Drop Pod Mission Manager")
        log.info(f"Target: {config.TARGET_LAT:.6f}, {config.TARGET_LON:.6f}")

        # Initialise sub-systems
        self.fc = FC_Link(config.FC_UART_PORT, config.FC_UART_BAUD)
        self.tracker = RedCarpetTracker()
        self.reachability = ReachabilityChecker()

        await self.fc.connect()

        # Spawn tasks
        tasks = [
            asyncio.create_task(self._telemetry_loop()),
            asyncio.create_task(self._state_machine_loop()),
            asyncio.create_task(self._heartbeat_loop()),
            asyncio.create_task(self._watchdog_loop()),
        ]

        try:
            await asyncio.gather(*tasks)
        except asyncio.CancelledError:
            log.info("Mission tasks cancelled — shutting down")
        finally:
            await self._shutdown()

    # ────────────────────────────────────────────────────────────
    # TELEMETRY LOOP
    # ────────────────────────────────────────────────────────────

    async def _telemetry_loop(self):
        """Continuously read MAVLink messages from FC and update telemetry."""
        log.info("Telemetry loop started")
        while self._running:
            msg = await self.fc.read_message()
            if msg is None:
                await asyncio.sleep(0.001)
                continue

            t = self.telemetry

            if msg.get_type() == "GLOBAL_POSITION_INT":
                t.lat     = msg.lat / 1e7
                t.lon     = msg.lon / 1e7
                t.alt_msl = msg.alt / 1000.0
                t.alt_agl = msg.relative_alt / 1000.0
                t.vx      = msg.vx / 100.0
                t.vy      = msg.vy / 100.0
                t.vz      = msg.vz / 100.0
                t.gps_fix = True

            elif msg.get_type() == "ATTITUDE":
                import math
                t.roll_deg  = math.degrees(msg.roll)
                t.pitch_deg = math.degrees(msg.pitch)
                t.yaw_deg   = math.degrees(msg.yaw)

            elif msg.get_type() == "GPS_RAW_INT":
                t.gps_fix  = msg.fix_type >= 3
                t.gps_hdop = msg.eph / 100.0

            elif msg.get_type() == "SYS_STATUS":
                t.battery_v   = msg.voltage_battery / 1000.0
                t.battery_pct = msg.battery_remaining

            elif msg.get_type() == "SCALED_IMU":
                import math
                accel_mag = math.sqrt(msg.xacc**2 + msg.yacc**2 + msg.zacc**2) / 1000.0
                t.accel_g = accel_mag / 9.81

            elif msg.get_type() == "RC_CHANNELS":
                t.rc_arm_high   = msg.chan7_raw  > config.RC_HIGH_THRESHOLD_US
                t.rc_drop_high  = msg.chan8_raw  > config.RC_HIGH_THRESHOLD_US
                t.rc_abort_high = msg.chan9_raw  > config.RC_HIGH_THRESHOLD_US

            t.timestamp = time.time()

    # ────────────────────────────────────────────────────────────
    # STATE MACHINE LOOP
    # ────────────────────────────────────────────────────────────

    async def _state_machine_loop(self):
        """Core mission FSM — transitions based on telemetry and commands."""
        log.info("State machine loop started")

        while self._running:
            await asyncio.sleep(0.05)  # 20 Hz FSM tick
            t = self.telemetry
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
